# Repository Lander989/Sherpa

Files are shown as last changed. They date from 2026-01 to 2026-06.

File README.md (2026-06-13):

# SHERPA
*Tactiele GPS: een navigatiesysteem voor blinden en slechtziende dat hen tijdens hun traject begeleidt aan de hand van een tactiele wijzer dat hen de weg toont.* 

🛠️ Built by ``Corbin Braekevelt`` & ``Lander Dumont`` & ``Roland Derynck``    
🔥 Supervised by ``prof. dr. Bas Baccarne``, ``Yannick Christiaens`` & ``Wouter Devriese``    
🌱 Grown at ``Ghent University`` 🏛️ ``Industrial Design Engineering`` ([project overview](https://github.com/basbaccarne/human-centered-design))       

*14/06/2026 van de laatste update*   

## Samenvatting
Personen met een visuele beperking ervaren vaak onzekerheid tijdens het navigeren. Huidige hulpmiddelen zoals spraak-GPS vragen veel concentratie (hoge cognitieve belasting), terwijl de gebruiker vooral behoefte heeft aan geruststelling en context op aangeleerde trajecten.

Ons onderzoek werd via het Triple Diamond-model uitgevoerd. Na veldonderzoek, interviews en testen bleek dat onze eerste poging, de tactiele kaart (wave 1) te complex was om te interpreteren tijdens het wandelen. Dit leidde tot een cruciale pivot naar *SHERPA*: een intuïtief navigatietoestel met een fysiek draaibare pijl, gebaseerd op het ‘Record & Replay’-principe.

**Record:** De gebruiker (of begeleider) wandelt een traject eenmalig af. Het toestel mapt automatisch de route. Herkenningspunten en obstakels worden via spraakberichten toegevoegd, waarna de route wordt opgeslagen in een persoonlijke keuzelijst.

**Replay:** De gebruiker selecteert een traject. De pijl, aangestuurd door de ingebouwde IMU en het kompas, wijst continu de juiste richting aan. Hierdoor vallen complexe instructies weg. Dit voelbare, constante oriëntatiepunt zorgt voor mentale rust en meer zelfvertrouwen, zonder onnodige afleidingen.

> *Om dit binnen de scope van het project te realiseren, werd er voor het finale prototype voor gekozen om uitsluitend de replay-fase integraal uit te werken aan de hand van de drie develop-fases.*

<p align="center">
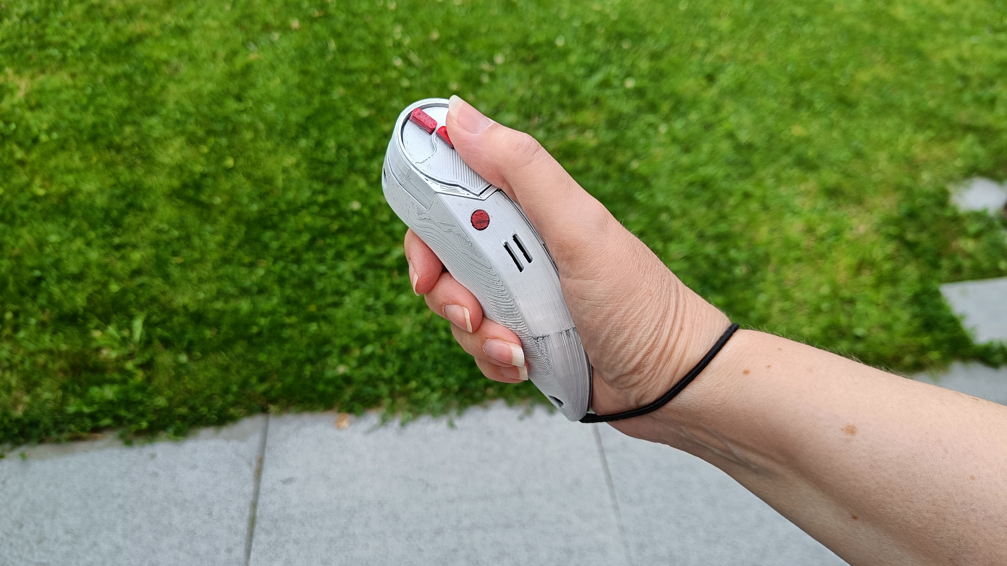
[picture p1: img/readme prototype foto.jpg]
  
</p>

## Introductie

De snelle digitalisering van de samenleving biedt kansen, maar creëert ook het risico dat personen met een visuele beperking worden uitgesloten wanneer interfaces niet toegankelijk zijn (Abdelkhalek, 2019)[^1]. Hoewel er diverse navigatiehulpmiddelen bestaan, blijft autonome navigatie in een veranderlijke omgeving een grote opgave. Het continu verwerken van complexe omgevingsinformatie vergt vaak een extreem hoge cognitieve inspanning, wat leidt tot mentale vermoeidheid en onzekerheid bij de gebruiker (Brayda et al., 2018)[^2].

Het doel van dit project is de ontwikkeling van een intuïtief hulpmiddel dat blinde personen ondersteunt bij het aanleren en onderhouden van trajecten. De focus ligt hierbij niet louter op het bereiken van een bestemming, maar op het bieden van context en geruststelling tijdens de verplaatsing. Door de mentale belasting (cognitive load) te minimaliseren, willen we de autonomie en het zelfvertrouwen van de gebruiker vergroten, zodat zij zich veiliger voelen in de openbare ruimte.

Een cruciale randvoorwaarde is dat de oplossing functioneert als aanvulling op de witte stok, specifiek voor buitengebruik (outdoor navigation). Het ontwerp moet blindelings en met één hand bedienbaar zijn, zodat het gehoor vrij blijft en de fysieke veiligheid van de gebruiker te allen tijde gewaarborgd is.

## Inhoudstafel

1. [Methodologie](./docs/methodologie.md)
2. [Discovery](./docs/discovery.md)
3. [Defintion](./docs/definition.md)
4. [Develop](./docs/develop.md)
5. [Opkomende Technologie](./docs/Opkomende%20Technologieën.md)
6. [Bill of materials](./docs/bom.md)
7. [Design Requirements](./docs/design_requirements.md)
## Kritische reflectie

<p align="center">
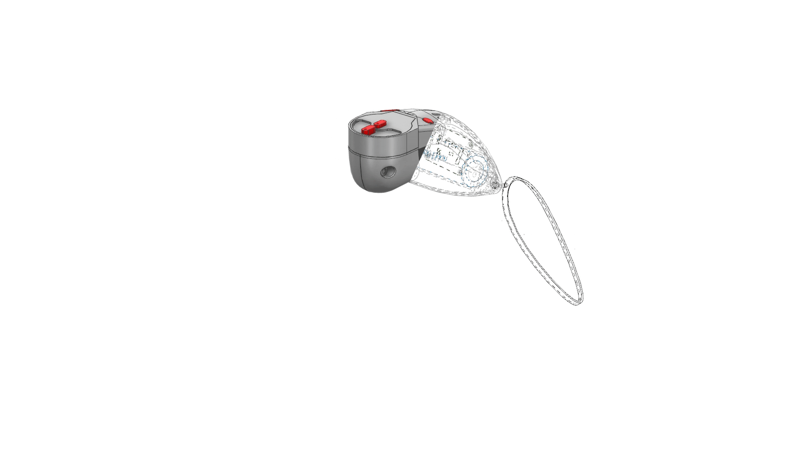
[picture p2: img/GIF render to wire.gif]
  
</p>

##### Semester 1:

Als we terugkijken op het proces van het eerste semester, was de keuze om te pivoten van de tactiele matrix naar de pijl zonder twijfel het kantelpunt. We hebben in het begin veel tijd gestoken in het matrix-concept, om er tijdens de Think Aloud-testen achter te komen dat dit cognitief veel te zwaar was voor de gebruiker. Deze validatieslag was cruciaal om te beseffen dat de gebruiker eigenlijk geen kaart wil ontcijferen, maar vooral op zoek is naar geruststelling en eenvoudige richting.

Toch moeten we kritisch zijn op onze validatie in de laatste fase. De Wizard of Oz-methode in wave 2 was perfect om het gevoel van de pijl te testen, maar het verhult de technische realiteit. Omdat wij zelf de pijl bestuurden, hielden we geen rekening met factoren zoals GPS-signaalverlies of onnauwkeurigheid in een stedelijke omgeving. We hebben dus wel de gebruikerservaring (UX) gevalideerd, maar de technische haalbaarheid is een risico dat we doorschuiven naar het volgende semester.

Daarnaast is onze testgroep (N=4) vrij homogeen gebleven. Onze respondenten, zoals Pieter-Jan, zijn al erg zelfstandig en mobiel. Hierdoor bestaat het risico dat we een oplossing hebben ontworpen voor een ‘best-case scenario’. Het is voor ons een belangrijk werkpunt om in de toekomst te testen met mensen die onzekerder zijn in het verkeer, om te zien of het ‘Record & Replay’-concept hen ook voldoende vertrouwen biedt.
##### Semester 2 
Aan het einde van de definitiefase concludeerden we dat ons product zich meer moest richten op blinden en slechtzienden die minder zelfredzaam en onzekerder in het verkeer zijn. In de praktijk bleek deze specifieke subdoelgroep echter uiterst moeilijk te bereiken, mede doordat zij zich minder vaak aansluiten bij belangenverenigingen. Hierdoor is het ons helaas niet gelukt om hen actief in ons verdere ontwerpproces te betrekken.

De waarde van continue, directe input vanuit de doelgroep kan simpelweg niet overschat worden. Dat we naar het einde van het project toe het contact met enkele van onze kerngebruikers verloren, was dan ook een flink nadeel. Dit had een direct negatieve impact op het afronden van ons onderzoek en bemoeilijkte het nemen van finale designbeslissingen.

Deze factoren hebben er mede toe geleid dat we onze vooropgestelde einddoelen niet volledig hebben behaald. Tijdens de finale outdoortesten kwamen bovendien technische pijnpunten aan het licht, waarbij vooral de onnauwkeurigheid van de GPS een aanzienlijk struikelblok vormde. Hoewel het huidige prototype een sterke basis vormt en de absolute meerwaarde van het concept aantoont, is het product technisch gezien nog lang niet klaar voor een marktintroductie.

Desondanks kijken we bijzonder positief terug op dit project. We hebben de kans gekregen om ons onder te dompelen in een voor ons compleet nieuwe wereld en we hebben enorm inspirerende mensen ontmoet. Bovenal heeft het ons als ontwerpers een veel scherpere en kritische blik gegeven op de manier waarop de maatschappij—en onze fysieke leefomgeving—zich al dan niet aanpast aan personen met een visuele beperking.

## Noot inzake het gebruik van AI
Binnen dit project is Gemini ingezet als ondersteunende AI-tool, met een strikt afgebakende rol:

* **Rapportage:** Het structureren van ruwe notities en het taalkundig verfijnen van teksten.
* **Development:** Ondersteuning bij het schrijven van de HTML-website.

> *AI werd nadrukkelijk niet ingezet voor inhoudelijke analyses of het bepalen van ontwerpbeslissingen en design requirements; deze fundamenten zijn uitsluitend gebaseerd op direct veldonderzoek en kritische teamreflectie.*

## Bijlagen
#### Discovery
* Literatuuronderzoek (N=16)

  [- Lander: Protocol literatuurstudie](<./reports and protocols/Protocol Literatuur Studie.pdf>)
  
  [- Roland: Protocol benchmarking](<./reports and protocols/Competitor analysis.pdf>)
  
  [- Corbin: Protocol benchmarking](<./reports and protocols/benchmarking_protocol_corbin_braekevelt.pdf>)
    
  [- Lander: Rapport literatuurstudie](<./reports and protocols/Rapport Literatuur Studie.pdf>)
  
  [- Roland: Rapport benchmarking](<./reports and protocols/Competitor analysis.pdf>)
  
  [- Corbin: Rapport benchmarking](<./reports and protocols/benchmarking_raport_corbin_braekevelt.pdf>)
* Interviews (N=12)

   [- Lander: Protocol interviews](<./reports and protocols/Protocol Interviews.pdf>)
  
   [- Roland: Protocol interviews](<./reports and protocols/Interviewprotocol_slechtzienden_!.pdf>)
  
   [- Corbin: Protocol interviews](<./reports and protocols/Interview-protocol-Corbin_Braekevelt.pdf>)

   [- Lander: Rapport interviews](<./reports and protocols/Rapport Interviews.pdf>)
  
   [- Roland: Rapport interviews](<./reports and protocols/Analyse respondenten rapport.pdf>)
  
   [- Corbin: Rapport interviews](<./reports and protocols/Interview-raport-Corbin_Braekevelt.pdf>)
    
#### Definition
* User testing wave 1 (N=6)
  * [Protocol](<./reports and protocols/Protocol Wave 1.pdf>)
  * [Rapport](<./reports and protocols/Verslag_wave1.pdf>)
* User testing wave 2 (N=2)
  * [Protocol](<./reports and protocols/Protocol Wave 2.pdf>)
  * [Rapport](<./reports and protocols/Rapport Wave 2.pdf>)

#### develop
* User testing develop 1 (N=5)
  * [protocol](<./reports and protocols/protocol_Deelopdracht 3 develop 1.pdf>)
  * [rapport](<./reports and protocols/Verslag_Deelopdracht 3 develop 1.pdf>)

* User testing develop 2 (N=5)
  * [protocol](<./reports and protocols/protocol_develop_2.pdf>)
  * [rapport](<./reports and protocols/Rapport_develop_2.pdf>)

* User testing develop 3 (N=2)
  * [protocol](<./reports and protocols/protocol_develop_3.pdf>)
  * [rapport](<./reports and protocols/Rapport_develop_3.pdf>)

## Licentie

This repository contains both software and design materials created as part of an industrial design energineering project at Ghent University.

- **Software and code:** [MIT License](./LICENSE-MIT)  
- **Design, documentation, CAD, and media:** [CC BY 4.0 License](./LICENSE)
  
You are free to reuse and build upon this work, both commercially and non-commercially, as long as proper attribution is given to the original authors.

## Bronnen
 [^1]:Abdelkhalek, M. (2019). Final Year Project Report - Blind Pad. University of Bath

 [^2]:Brayda, L. et al. (2018). Updated Tactile Feedback with a Pin Array Matrix. Micromachines, 9(7), 351

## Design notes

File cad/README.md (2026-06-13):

# SHERPA — CAD & 3D-Modellen

In de map `cad` vind je zowel het ZIP-archief van ons project met de originele PRT-bestanden (Siemens NX), als de STL-bestanden die volledig gereed zijn voor 3D-printing.

### Beschikbare bestanden:
* **Compleet CAD-model:** [SHERPA assembly](./PRT/Sherpa_Final.zip)
* **STL-bestanden:**

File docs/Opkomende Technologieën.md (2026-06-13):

# Opkomende Technologieën
## Inleiding
In het kader van het vak Opkomende Technologieën (OT) werken we een MVP-variant uit van de SHERPA-wegwijzer uit het project Gebruiksgericht Ontwerpen (GGO). In het vak OT is de onderbouwing uit GGO minder van toepassing. De nadruk ligt op het uitwerken van een technisch uitdagend prototype waarbij verschillende competenties worden getoetst en samenkomen.

### GGO
Het product en doelstellingen uit GGO zien er als volgt uit:

**Product:** Navigatiehulpmiddel voor blinden en slechtzienden

**Doel:**
Gebruikers een manier geven om sneller en zelfstandiger onbekende routes aan te leren en onderhouden.

Productdoelstellingen:
1. Gebruikers kunnen een traject zelfstandig afleggen zonder hulp van derden  
2. Gebruikers kunnen met hulp van derden trajecten opnemen  
3. Gebruikers ervaren continu oriëntatie en vertrouwen tijdens het gebruik  
4. Gebruikers blijven fysiek veilig tijdens navigatie  
5. Het systeem vereist minimale training en mentale inspanning

<p align="center">
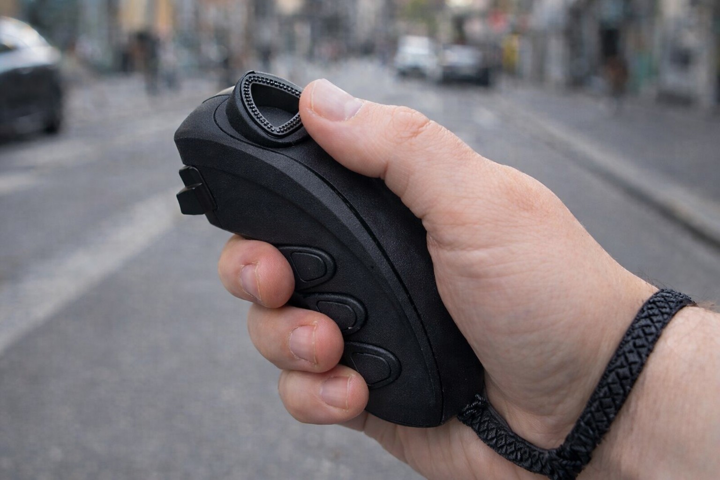
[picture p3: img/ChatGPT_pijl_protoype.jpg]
  
  <br>
  <em>Visualisatie van de SHERPA-wegwijzer.</em>
</p>

Dit heeft zich kortweg vertaald naar een mobiel navigatiesysteem dat met een wijzer de weg wijst doorheen een opgenomen traject. Op deze wijze wordt een blinde van punt naar punt via de veiligste weg geleid. Hierover valt uitgebreid te lezen in het GGO-gedeelte van deze GitHub.

## Opdracht

Voor OT kijken we naar de technische uitdagingen. Dit zijn volgende punten:

- Waar is de persoon: GPS data uitlezen intepreteren en gebruiken.

- Traject opslaan: Data opslaan en opnieuw ophalen.

- Naar waar kijkt de persoon: Kijkrichting van de gebruiker bepalen met een IMU.

- Wijzer richten: Servo aansturen zodat deze altijd naar het volgende waypoint wijst.

- Algemene besturing van toestel: Inputs toevoegen zodat de gebruiker het toestel kan gebruiken.

- Op afstand het systeem uitlezen en de data weergeven op een HMI: Connectiviteit wifi/bluethoot, dashbord waar data weergegeven wordt om troubleshooting te bevorderen.

## Richtingbepaling
Doel

De wijzer moet het volgende waypoint aanwijzen. Hier is de vraag: hoe weet de wijzer naar waar hij moet wijzen? De volgende afbeelding illustreert hoe de hoek bepaald wordt. Het magnetische noorden dient als nullijn. In wijzerszin loopt de hoek van 0 tot 360 graden op. Soms komen [0,180] en [-180,0] voor in de berekeningen. Onthoud dat de heading en bearing altijd genormaliseerd worden naar een waarde tussen 0 en 360 graden. Het verschil tussen de heading en bearing noemen we delta. Met delta kan theta gevonden worden. Theta stuurt de hoek van de servo.

Met een IMU bepalen we de heading. De bearing bepalen we aan de hand van de huidige locatie en het doelwit. De huidige locatie halen we op met een GPS. Het doelwit is een van de opgeslagen coördinaten.

<p align="center">
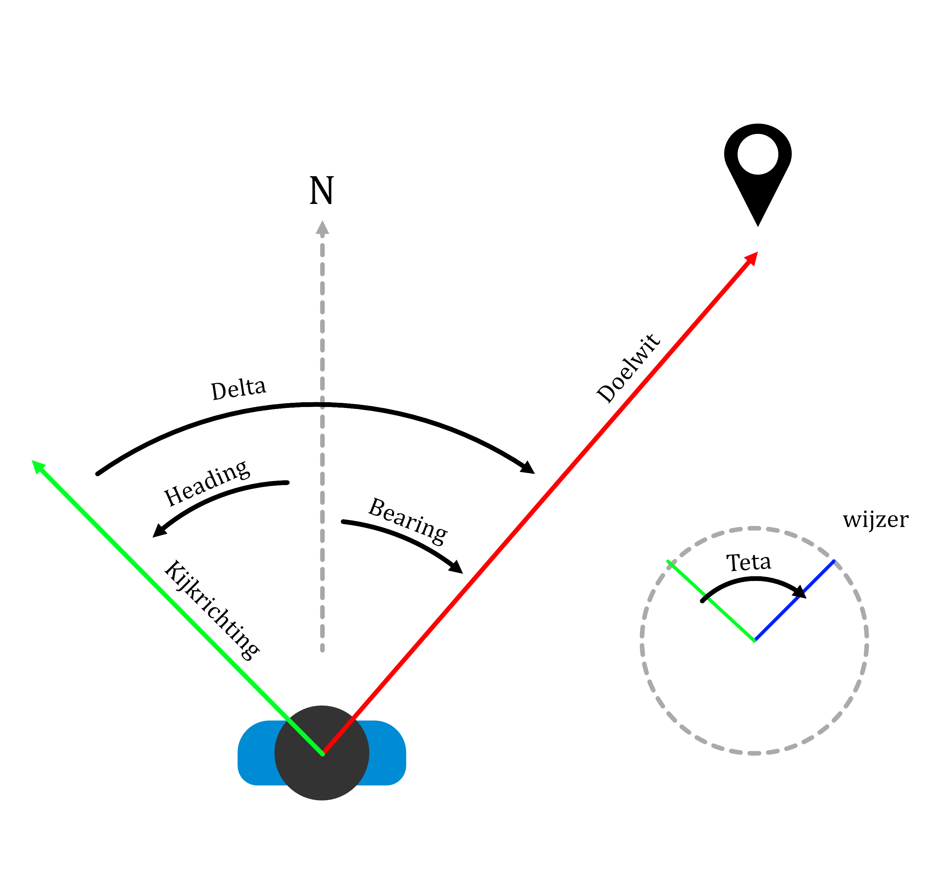
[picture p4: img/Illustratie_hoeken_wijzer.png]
  
  <br>
  <em>Illustratie van heading, bearing, delta en theta.</em>
</p>

## Onderdelen

#### IMU
We maken gebruik van een grove 9DOF-IMU. Deze sensor bevat een accelerometer, gyrometer en magnetometer.

De meegeleverde voorbeeldcode uit de bibliotheek is onbruikbaar. Deze bevat geen tiltcompensatie en sensorfusion. De volgende Instructables-post gebruiken we als basis om onze sensoren uit te lezen en om te zetten in nuttige, stabiele informatie.

>https://www.instructables.com/Tilt-Compensated-Compass/

Hiermee zijn we in staat om accuraat de kijkrichting van de persoon te bepalen, ongeacht de oriëntatie van de sensor.
#### GPS
De GPS is in staat om binnen de 2 meter zijn positie te bepalen. Dit coördinaat update constant. De bibliotheek TinyGPS++ bevat een bearingfunctie die bij ingave van twee coördinaten de bearing teruggeeft.

#### Inputs en outputs
De gebruiker bestuurt het toestel met twee knoppen. De knoppen zijn NO-drukknopjes. We verbinden ze met pulldownweerstanden aan de microcontroller. Het toestel bevat ook een trilmotor voor vibratiefeedback. De trilmotor wordt aangestuurd met een PWM-signaal. Dit maakt het mogelijk om verschillende patronen af te spelen.

####  Schakeling
Volgende afbeelding toont de schakeling schematisch.

<p align="center">
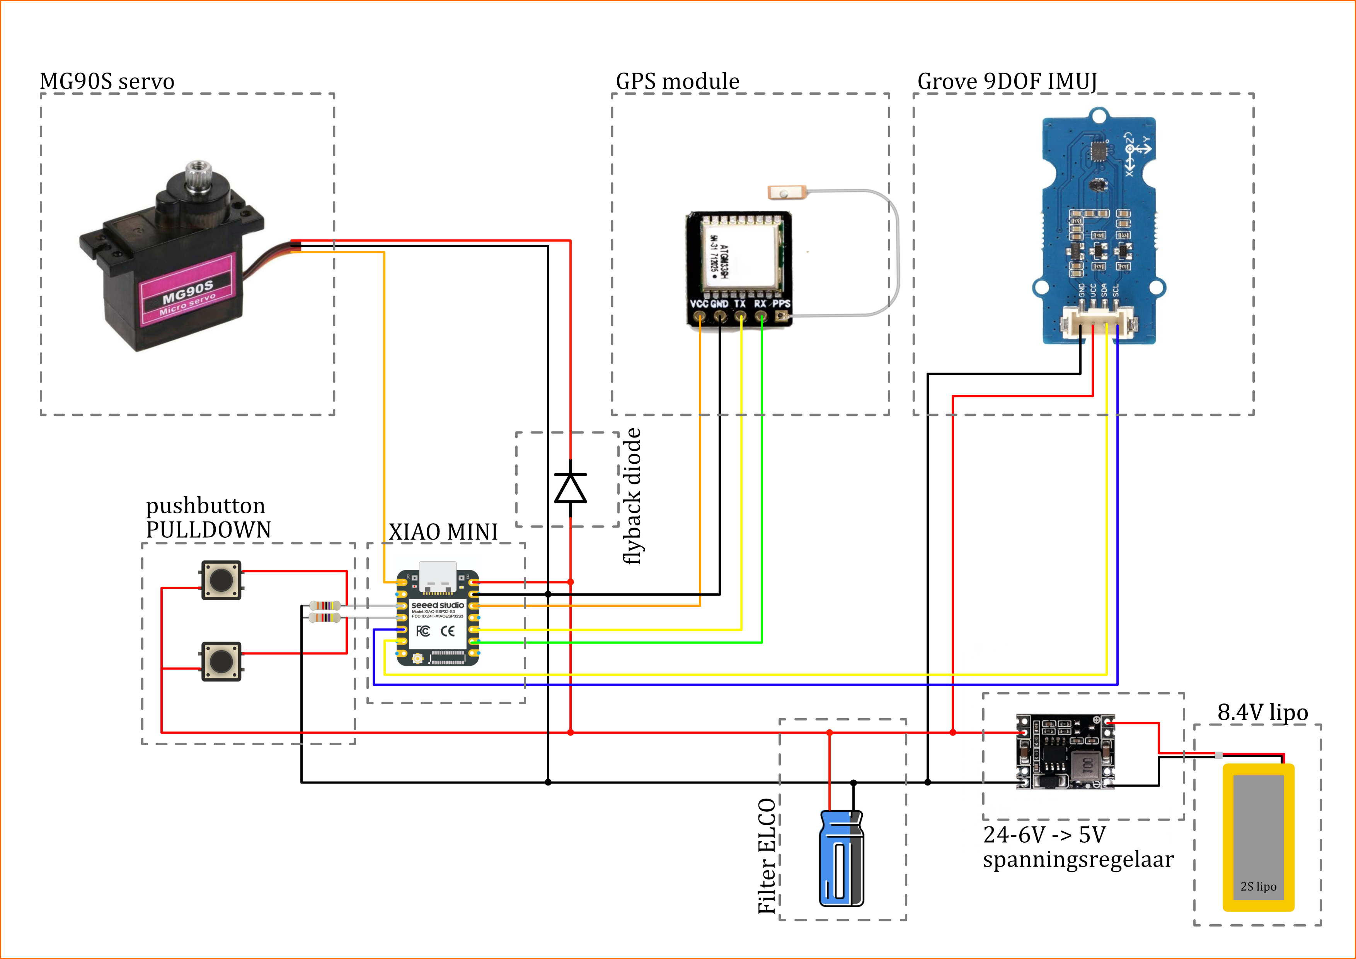
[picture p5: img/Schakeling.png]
  
  <br>
  <em>Schematische voorstelling van de schakeling.</em>
</p>
Dit schema uitgewerkt in een eerste prototype ziet er chaotisch uit. Maar alles is aanwezig om de functionaliteit te testen. Hierna kan de geteste en werkende versie in een afgewerkte omhuizing worden gestoken.
<p align="center">
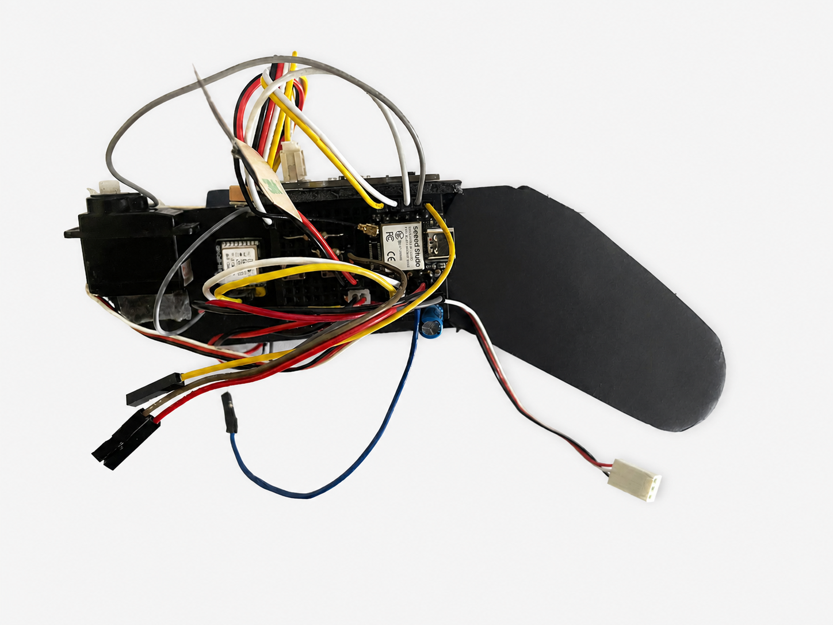
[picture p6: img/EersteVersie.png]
  
  <br>
  <em>Eerste werkende prototype van de schakeling.</em>
</p>

## Traject

Tijdens het ontwikkelen van de prototypes maakten we gebruik van Google Earth om routes uit te stippelen. Deze route bestaat uit een lange lijst van latitude- en longitudecoördinaten. Het toestel weet wanneer een punt gepasseerd wordt en schakelt vervolgens over naar het volgende waypoint.

Het is de bedoeling dat de gebruiker later zelf trajecten kan opnemen. Hierbij wordt de lijst met punten automatisch aangemaakt door het toestel terwijl een traject wordt afgelegd. Om de ongeveer 2 meter zou dan een nieuw punt worden opgeslagen. Deze functionaliteit werd echter niet verder uitgewerkt wegens tijdsgebrek. 

## Visualiseren van het traject
<p align="center">
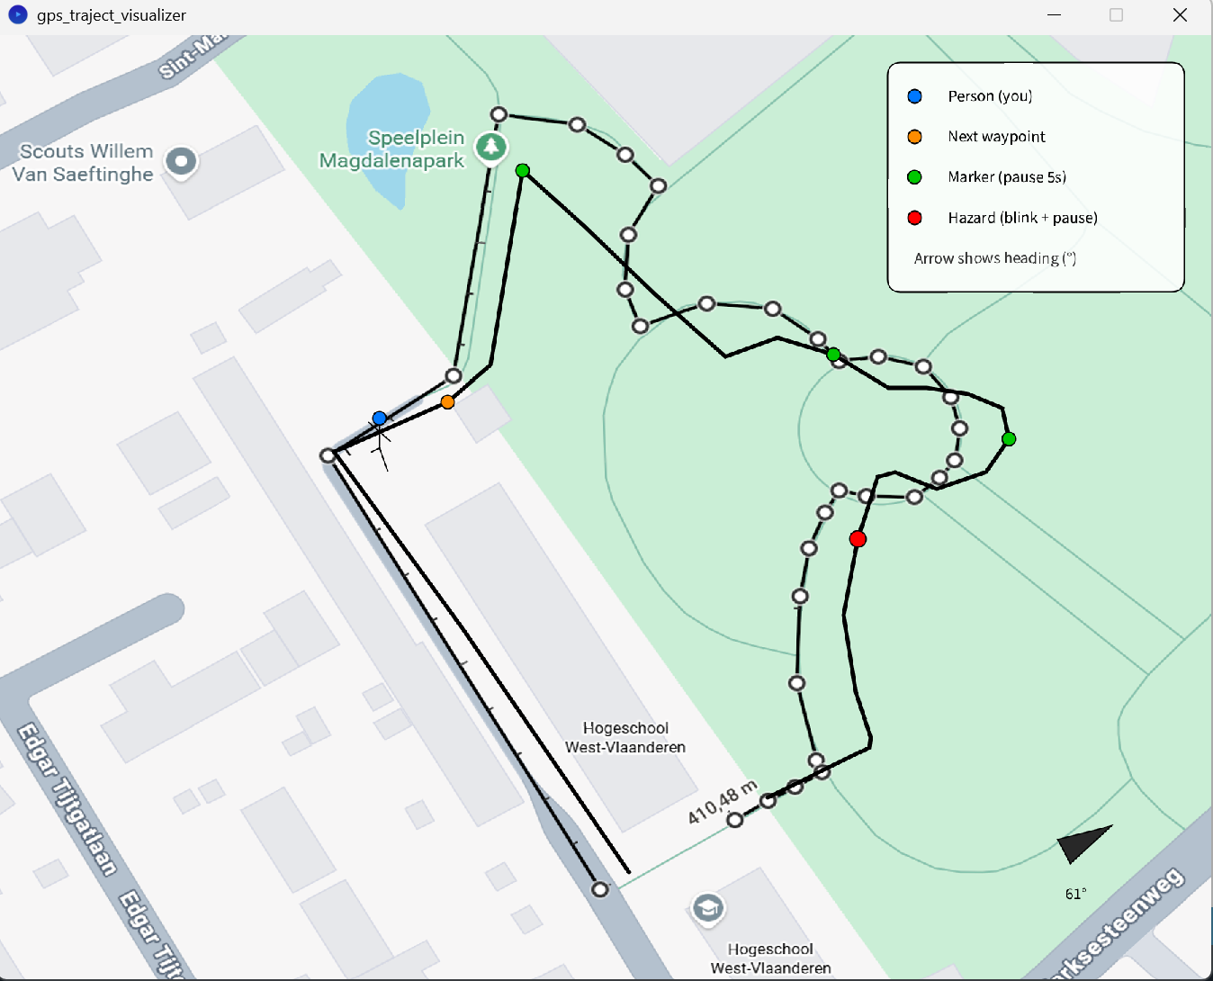
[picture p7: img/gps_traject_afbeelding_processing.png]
  
  <br>
  <em>Visualisatie van het GPS-traject in Processing.</em>
</p>
In de eerste fase van het project werd een visualisatie ontwikkeld in Processing. Hierbij werden GPS-datapunten handmatig geëxtraheerd uit Google Maps en ingelezen om het traject statisch uit te tekenen.

Het traject op de afbeelding komt, zoals te zien, niet volledig overeen met het traject op Google Maps. Dit komt door de platte 2D-weergave van onze kaart ten opzichte van de werkelijke 3D-kromming van de aarde, wat een verschuiving veroorzaakt. Daarnaast trekt onze weergave een rechte lijn tussen twee punten, waardoor bochten worden afgesneden.

Omdat de ESP32 fungeert als een lokale webserver en continu livecoördinaten doorstuurt, zijn we voor de definitieve opstelling overgestapt naar een dynamische, webgebaseerde (HTML-)visualisatie. Dit maakt het mogelijk om de ontvangen data veel efficiënter en in realtime weer te geven.

## Validatietest
Om de effectiviteit, integratie en nauwkeurigheid van het systeem in de praktijk te verifiëren, is het traject fysiek afgelegd tijdens een veldtest. De eerste GIF demonstreert de dynamische werking van de wijzer. Deze past zich in realtime aan op basis van de actuele kijkrichting (heading) van het toestel ten opzichte van het volgende waypoint.

<p align="center">
  
  <br>
  <em>Realtime aanpassing van de wijzer tijdens navigatie.</em>
</p>

De tweede GIF toont de navigatie door een scherpe bocht. Hierbij is te zien hoe de binnenkomende data van de ESP32 nauwkeurig wordt geregistreerd op het webdashboard, terwijl de fysieke wijzer synchroon en correct het volgende waypoint aanduidt.

<p align="center">
  
  <br>
  <em>Validatietest tijdens een scherpe bocht.</em>
</p>

## Afwerking

Het werkende prototype werd in een afgewerkte behuizing ingebouwd. Hiermee hebben we testen uitgevoerd voor het vak GGO.

<p align="center">
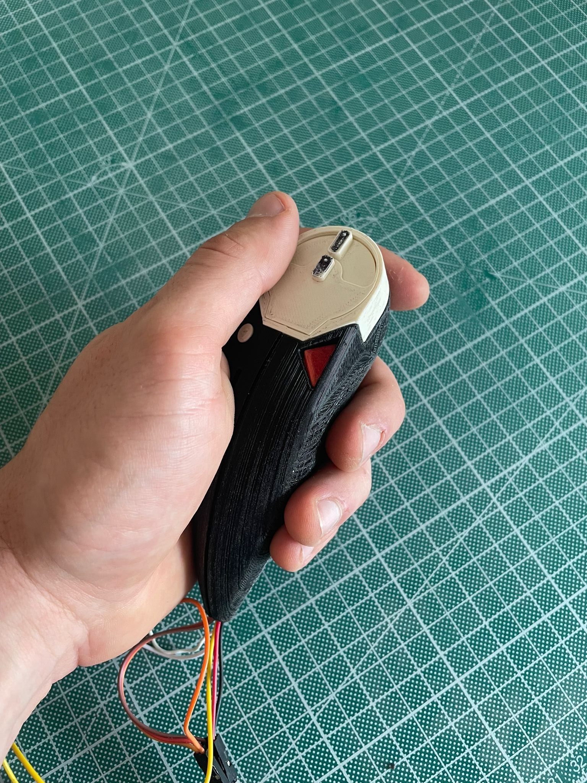
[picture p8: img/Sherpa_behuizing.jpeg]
  
  <br>
  <em>Afgewerkte behuizing van het prototype.</em>
</p>

## Code

Hier is de finale code: [GPS_IMU_TEST_V3_ESP32](https://github.com/Lander989/Sherpa/blob/main/src/Opkomende%20Technelogie%C3%ABn/GPS_IMU_TEST_V3_ESP32/GPS_IMU_TEST_V3_ESP32.ino)

## Kritische reflectie

Tijdens de finale test bleken er toch wat onnauwkeurigheden naar boven te komen, vooral bij de GPS, die maar accuraat is tot op 2 meter. Dit bracht vervelende situaties met zich mee, aangezien de punten die op Google Earth nog op het wandelpad lagen, zich tijdens de test soms in een gebouw of in de struiken bevonden.

Voor het einddoel van de Sherpa, namelijk het veilig navigeren van blinden en slechtzienden, vormt deze afwijking een kritiek punt.

Een mogelijke oplossing is de overstap naar een dualband-GPS-module. Deze modules combineren meerdere frequenties, waardoor ze aanzienlijk accurater zijn en minder last hebben van signaalreflecties dicht bij gebouwen of bomen.

De ESP32 gebruiken als lokale webserver was de simpelste manier om de data draadloos naar de computer te sturen. Maar dit komt met een groot nadeel dat tijdens het testen duidelijk werd. Zolang jouw laptop verbonden is met de ESP32, heb je geen internet. Hierdoor kunnen we de kaartafbeelding niet updaten.

Bluetooth Low Energy zou een betere optie zijn geweest. Maar we kregen de data niet uitgelezen op de computer. Daarom kozen we ervoor om de webserver te gebruiken.

## Noot inzake het gebruik van AI
In dit project werd Gemini Pro gebruikt bij het coderen van de visualisatie, zowel voor Processing als voor de finale HTML-website. Ook werd de tekst grammaticaal scherpgesteld door Gemini.

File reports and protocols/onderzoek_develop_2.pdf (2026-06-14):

# Sherpa develop 2 onderzoeksrapport

## Wat willen we onderzoeken in deze fase

- Nodige functies linken aan de nodige knoppen.

Het product moet instaat zijn om verschillende functies uit te voeren. Deze functies moeten gelinkt worden aan user inputs, deze zullen komen van verschillende knoppen (drukknoppen, slider, triggers, …) en andere componenten (zoals bv. een microfoon).
- Positie van de knoppen op product.

De gedefinieerde knoppen zullen ook hun eigen plaats op het product krijgen. De plaats van deze knoppen moet logisch en comfortabel zijn voor de gebruiker.
- Welke houding neemt de gebruiker aan.

Bij het gebruik van het product zal de gebruiker deze op een bepaalde manier vasthouden, dit zal onderzocht worden. Ook zal er gekeken worden naar hoe het product ervoor zorgt dan de gebruiker bewust of onbewust een comfortabele en ergonomische positie aanneemt.
- Vorm van het product aanpassen.

Doormiddel van prototypes de product vorm en button lay-out testen en verbeteren.
- Elektronica verwerken.

Kijken of alle nodige elektronica en componenten in het product passen. Zo niet een oplossing bedenken.

## Benchmarking

Elke controller is onderzocht op vorm, button layout en ergonomie.

## 1. DJI RC Motion 3

Vorm & Dimensies
- Compacte, handheld design speciaal ontworpen voor drone-besturing
- Gemiddelde lengte: ongeveer 15-17 cm
- Breedte: circa 8-10 cm
- Asymmetrisch ontwerp dat goed aansluit op de hand
Button Layout
- Twee analoge joysticks in het midden (thumbstick positie)
- Trigger-knoppen aan de bovenkant (voor duim bereikbaar)
- Multifunctionele knoppen aan de zijkanten

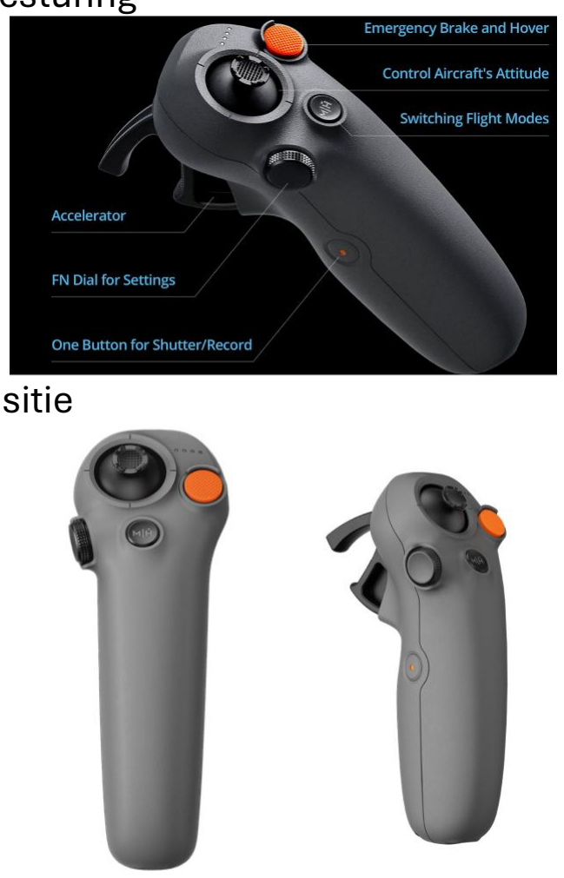
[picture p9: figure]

- Goed verspreide lay-out voor snelle toegang zonder hand-repositie Ergonomische Kenmerken
- Grip diameter: ongeveer 30-35 mm
- Grip lengte: geoptimaliseerd voor gemiddelde handen
- Ergonomische sculptuur voor palm- en vingerondersteuning
- Antislip materiaal op contactoppervlakken

## 2. Meta Quest 3 Touch Controller

Vorm & Dimensies
- Ergonomisch ontworpen voor VR-toepassingen
- Lengte: ongeveer 13-14 cm
- Grip omvang: 35-40 mm
- Geïntegreerde hand tracking band aan bovenkant Button Layout
- Joystick aan voorkant (duim-bereik)
- X/Y en A/B knoppen langs zijkant
- Grip-knoppen aan beide zijkanten (wijsvinger)
- Trigger aan voorkant (wijsvinger-bediening) Ergonomische Kenmerken
- Asymmetrisch design voor linker- en rechterhand
- Licht gewicht (circa 150g) voor langdurig gebruik
- Natuurlijke greep houding ondersteund door vorm

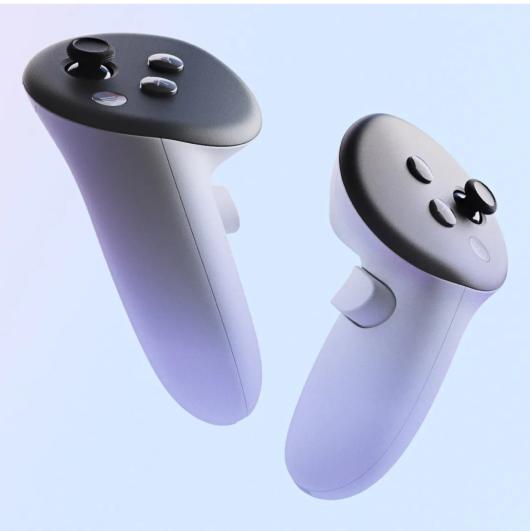
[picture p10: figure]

## 3. Nintendo Wii Remote

Vorm & Dimensies
- Rechthoekig, straight-bar design
- Lengte: ongeveer 15 cm
- Breedte: circa 5 cm
- Zeer compacte en lichte constructie
Button Layout
- D-pad aan voorkant
- A-knop en B-knop onder (duim + wijsvinger bereik)
- Home en Power knoppen aan bovenkant
- Zeer eenvoudige, minimalistische button-indeling Ergonomische Kenmerken
- Zeer licht gewicht (ongeveer 150g)

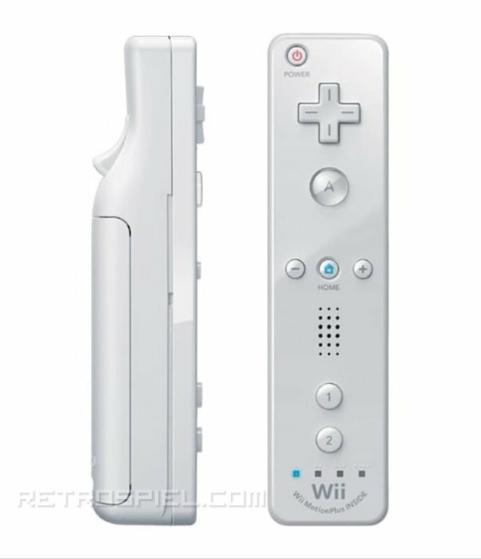
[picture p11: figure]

- Ingebouwde motion-sensoren (accelerometer, gyroscoop)
- Eenvoudige grip zonder veel anatomische sculptuur
- Geschikt voor alle leeftijden en handgroottes

## 4. PlayStation DualSense Controller

Vorm & Dimensies
- Symmetrisch, ergonomisch gebogen design
- Lengte: ongeveer 16 cm
- Breedte: ongeveer 11 cm
- Gewicht: circa 280g
Button Layout
- Twee analoge joysticks (standaard positie)
- Vier face-buttons (driehoek, cirkel, X, vierkant)
- Shoulder buttons (L1, R1, L2, R2)
- Touchpad aan bovenkant
- PlayStation-knop en options/share knoppen

Ergonomische Kenmerken
- Grip diameter: ongeveer 35-40 mm
- Grip lengte: ongeveer 120 mm
- Diepe grip curves voor comfort tijdens lang gebruik
- Textuur op grip-oppervlak
- Haptic feedback en adaptieve triggers

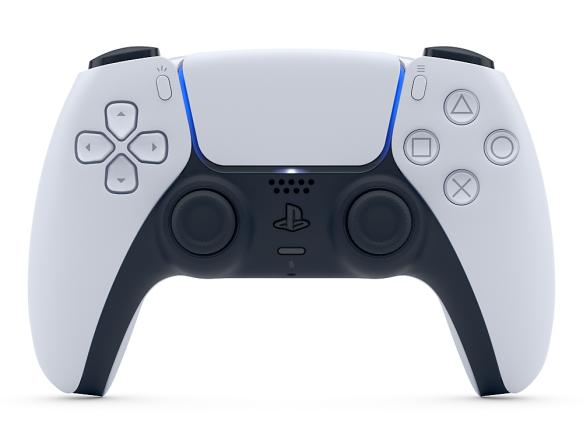
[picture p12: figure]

## Vergelijkende Analyse

Samenvatting per Categorie
Aspect | DJI RC Motion 3 | Meta Quest 3 | Wii Remote | DualSense
Grip Diameter | 30-35 mm | 35-40 mm | ~50 mm | 35-40 mm
Lengte | 15-17 cm | 13-14 cm | ~15 cm | ~16 cm
Symmetrisch | Nee | nee | Ja | Ja

Belangrijkste Inzichten
Grip Diameterrange
De onderzochte controllers variëren van 30-75 mm in grip diameter. De Sherpa design-doelstelling van 28-37 mm (op basis van het 5e percentiel) past goed in het onderste bereik, geschikt voor kleinere handen en precisiewerk.

Button Layout Strategie
Alle referentie-controllers gebruiken een combinatie van analoge inputs (joysticks) en discrete knoppen. De Wii toont dat minimalisme werkt voor brede doelgroepen.

## Mappen van inputs

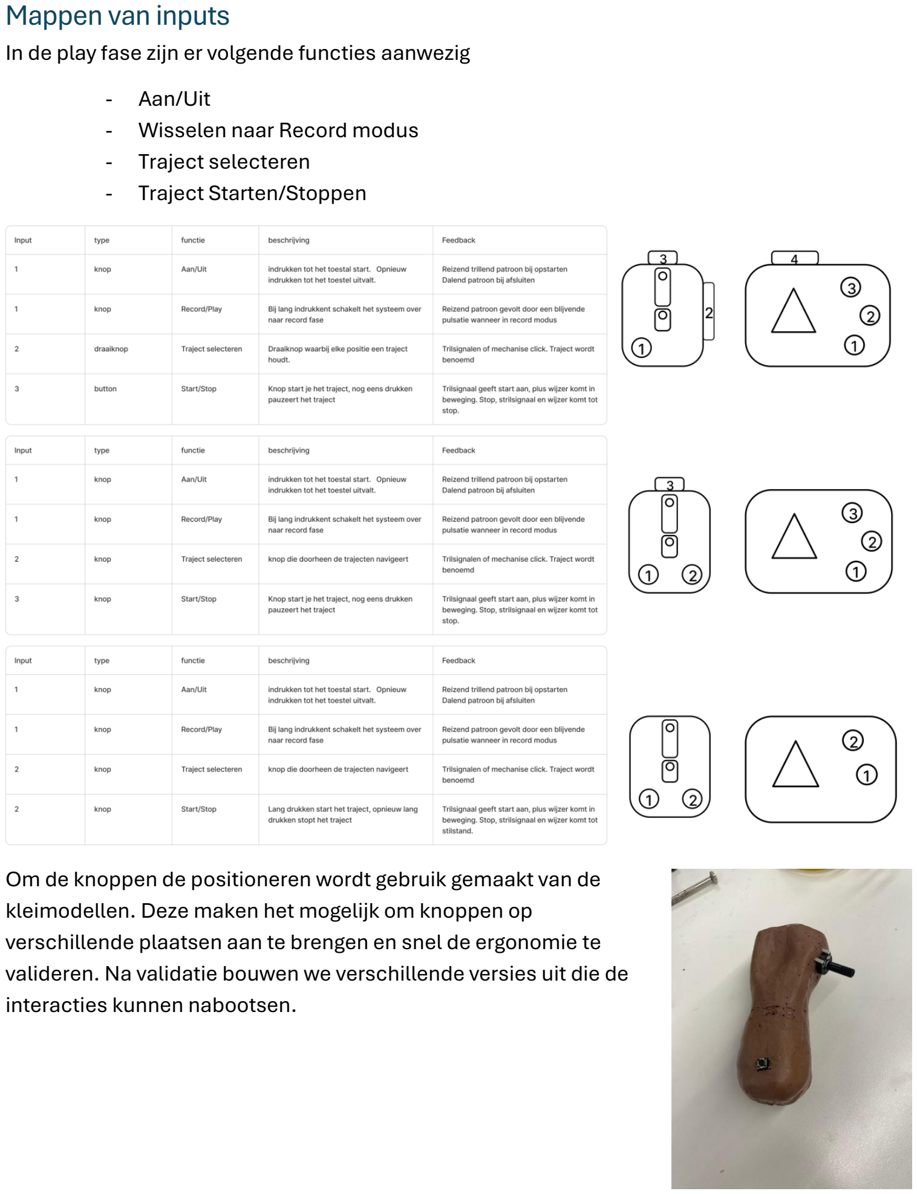
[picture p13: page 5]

In de play fase zijn er volgende functies aanwezig
- Aan/Uit
- Wisselen naar Record modus
- Traject selecteren
- Traject Starten/Stoppen

Om de knoppen de positioneren wordt gebruik gemaakt van de kleimodellen. Deze maken het mogelijk om knoppen op verschillende plaatsen aan te brengen en snel de ergonomie te valideren. Na validatie bouwen we verschillende versies uit die de interacties kunnen nabootsen.

## Ergonomie onderzoek

Rond ergonomie zijn er in het verleden al voldoende onderzoeken rond gebeurd. Voor deze opdracht is er dan ook geen tijd beschikbaar om zelf volwaardig onderzoek te doen rond de ergonomie van het lichaam, meebepaald de hand. Hierdoor wordt bij deze deelopdracht gebruikgemaakt van onderzoeken en researchpapers van andere onderzoekers. Antropometrische Data
De diameter van het handvat wordt ontworpen op
basis van het 5e percentiel, zodat zowel kleine als
grote handen het handvat comfortabel kunnen omvatten. Deze maat wordt enkel in de breedte aangeduid op de afbeelding gerespecteerd. In de lengte mag het groter zijn (richting van de wijsvinger). De lengte van het handvat wordt afgestemd op de handbreedte, waarbij het 95e percentiel wordt gehanteerd, zodat ook gebruikers met grotere handen het handvat volledig kunnen vastgrijpen.
De volgende data is afkomstig van de DINED-database:

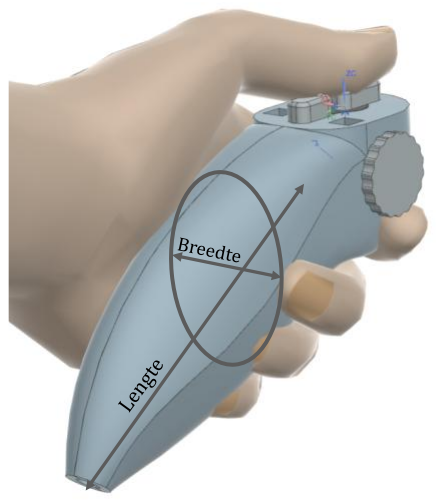
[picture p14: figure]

Tilley en Dreyfuss hebben in hun onderzoek "The Measure of Man and Woman" (1974) gedetailleerde afmetingen van mannelijke en vrouwelijke handen gedocumenteerd. Deze data omvatten kritieke maten zoals handlengte, handbreedheid, en vingerlengtes. Robinson (in het "Anthropometric Hand Measurements") complementeert dit met aanvullende afmetingen voor grip-analyse.

Percentiel | 5% | 50% | 95%
Greep diameter | 34,37 | 41,06 | 47,75
Handbreedte | 71 | 84 | 97

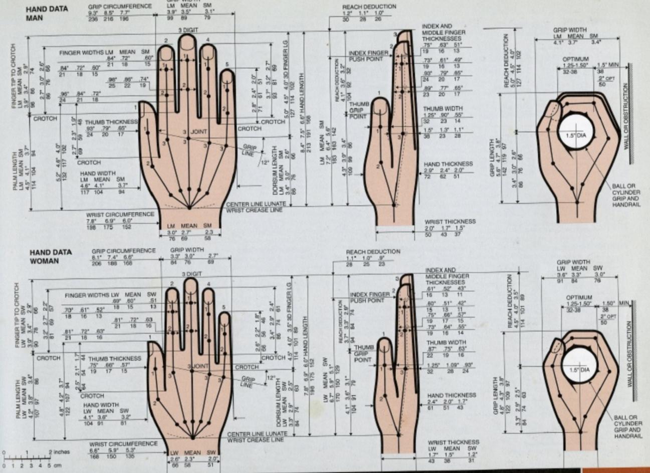
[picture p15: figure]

Een gemiddelde mannelijke handlengte bedraagt ongeveer 188,8 mm, terwijl vrouwelijke handen gemiddeld 182,1 mm zijn. De handbreedheid varieert van ongeveer 72,5 mm (vrouw) tot 86,5 mm (man). Deze variatie is essentieel voor het ontwerp van een product dat voor diverse gebruikers ergonomisch geschikt is.
Greep geometrie
Onderzoeken tonen aan dat de optimale handvatdiameter tussen 28-37 mm ligt voor een neutrale greephouding. De waarde van het gekozen percentiel valt met 34 mm hier in. González et al. (2018) demonstreerden dat een geparametriseerde handvatontwerp, geschaald naar individuele palmlengte (PLM), optimale ergonomie oplevert. Voor de PLM is er geen dataset te vinden.
Voor langdurig gebruik is een cilindrisch of licht anatomisch gevormde handgreep essentieel. De greep moet voldoende contactoppervlak bieden om druk evenwichtig over palm en vingers te verdelen. Dit minimaliseert vermoeiding en voorkomt concentratie van druk op gevoelige gebieden.

De handvatlengte zou minimaal 100-120 mm bedragen om voldoende stabiliteit en controle te bieden. De waarde van het gekozen percentiel komt hier ongeveer mee overeen.
Een helling van 45° tussen handvat en de voorkant van het product zorgt voor een natuurlijke polshouding.

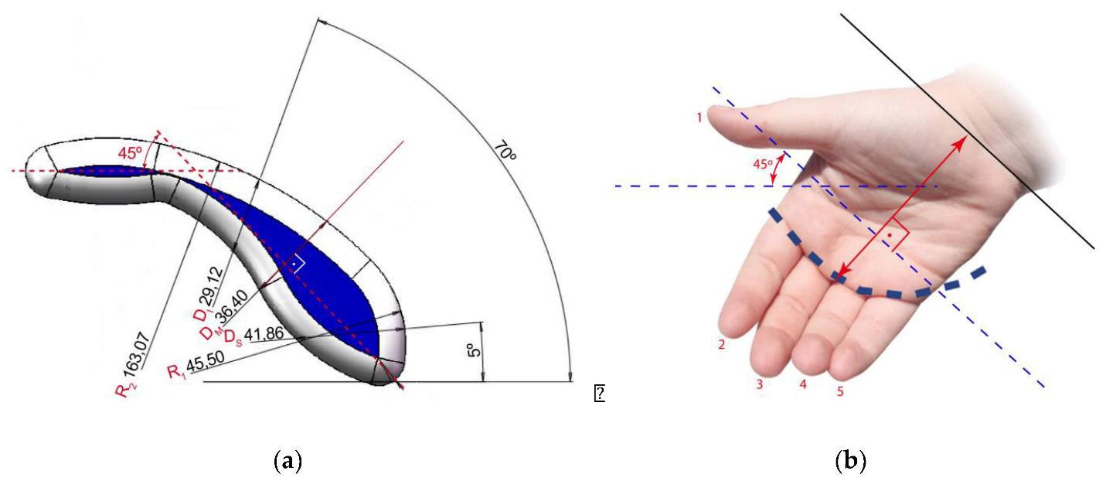
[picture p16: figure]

Knoppen dienen gepositioneerd te worden in bereik van duim, wijsvinger en middelvinger in neutrale hand-positie. Op basis van antropometrische data:
- Duim: bereik van 0-40 mm vanaf palmzijde
- Wijsvinger: bereik van 50-80 mm langs bovenzijde handvat
- Middelvinger: bereik van 30-60 mm vanaf palmzijde
Knoppen voor frequent gebruik moeten zich op maximaal bereikbare posities bevinden zonder polsflexie.
Langdurig controllergebruik vereist een neutrale polshouding. Dit betekent:
- Pols in lichte extensie (5-10°)
- Geen radiale of ulnaire deviatie
- Elleboog flexie van ongeveer 90°
- Arm steun op gewenste hoogte
Het productontwerp dient deze houding passief te ondersteunen, zodat gebruikers zich kunnen concentreren op de interactie zonder fysieke compensatie.

Conclusie

Voor dit project kan er dus gebruikgemaakt worden van deze bevindingen. De belangrijkste afmetingen om rekening me te houden zijn dus: een diameter van 28-37 mm, lengte van minimaal 110 mm, en anatomisch optimale knopplaatsing. Het toepassen van deze maten zorgen voor langdurig comfortabel gebruik.

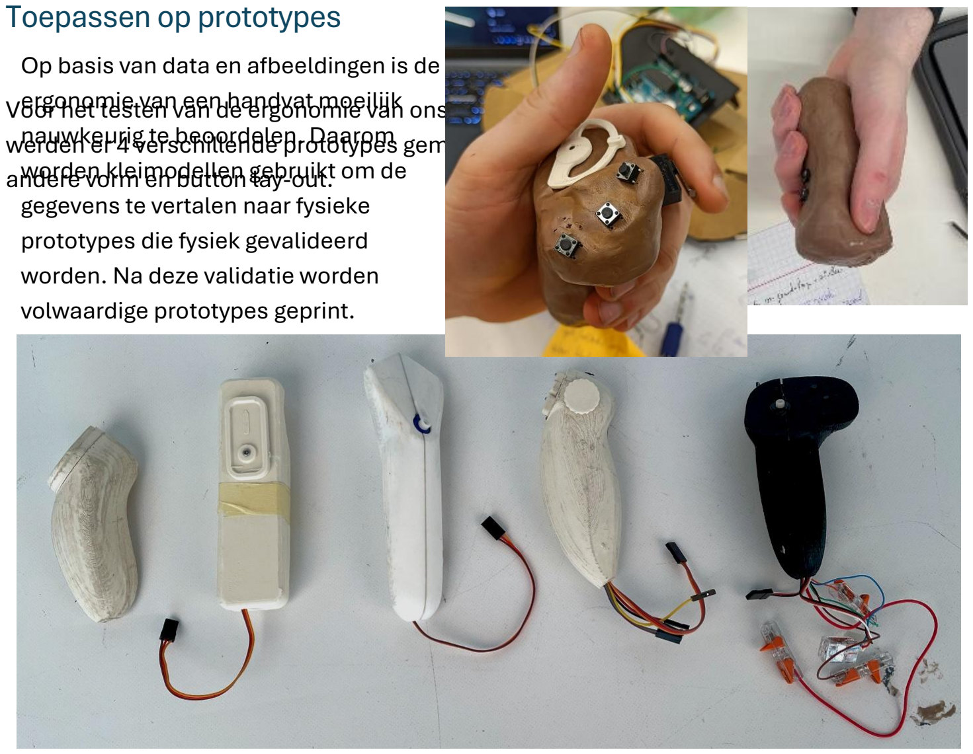
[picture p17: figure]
Toepassen op prototypes; andere vorm en button lay-out.; Op basis van data en afbeeldingen is de ergonomie van een handvat moeilijk nauwkeurig te beoordelen. Daarom worden kleimodellen gebruikt om de gegevens te vertalen naar fysieke prototypes die fysiek gevalideerd worden. Na deze validatie worden volwaardige prototypes geprint.

Voor het testen van de ergonomie van ons product bij de doelgroet werden er 4 verschillende prototypes gemaakt worden met elk een

Prototypes
Type 1:

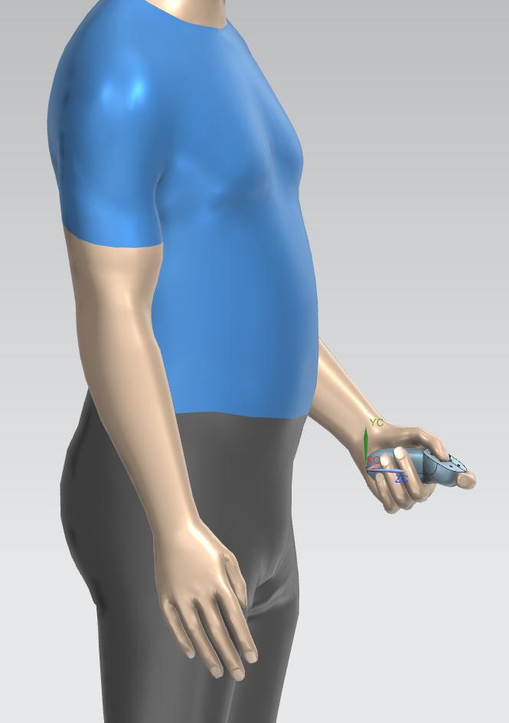
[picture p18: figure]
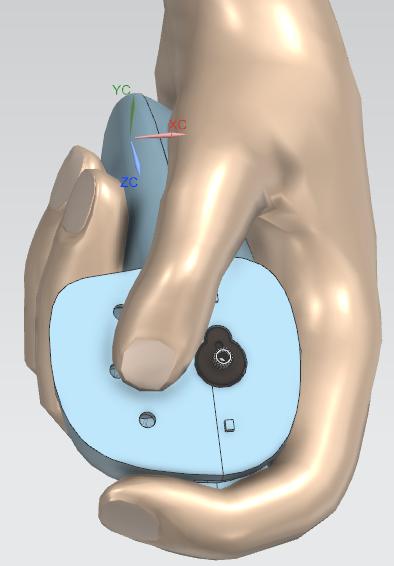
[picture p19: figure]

Deze versie van het product is sterk gebaseerd op een VR controller. Hierbij is plaats voorzien voor de richtingswijzer met daarnaast drie knoppen om het toestel te bedienen, aan de voorzijde is ook een trigger voorzien als extra input. De nominale maten werden toegepast bij het ontwerpen van deze versie.

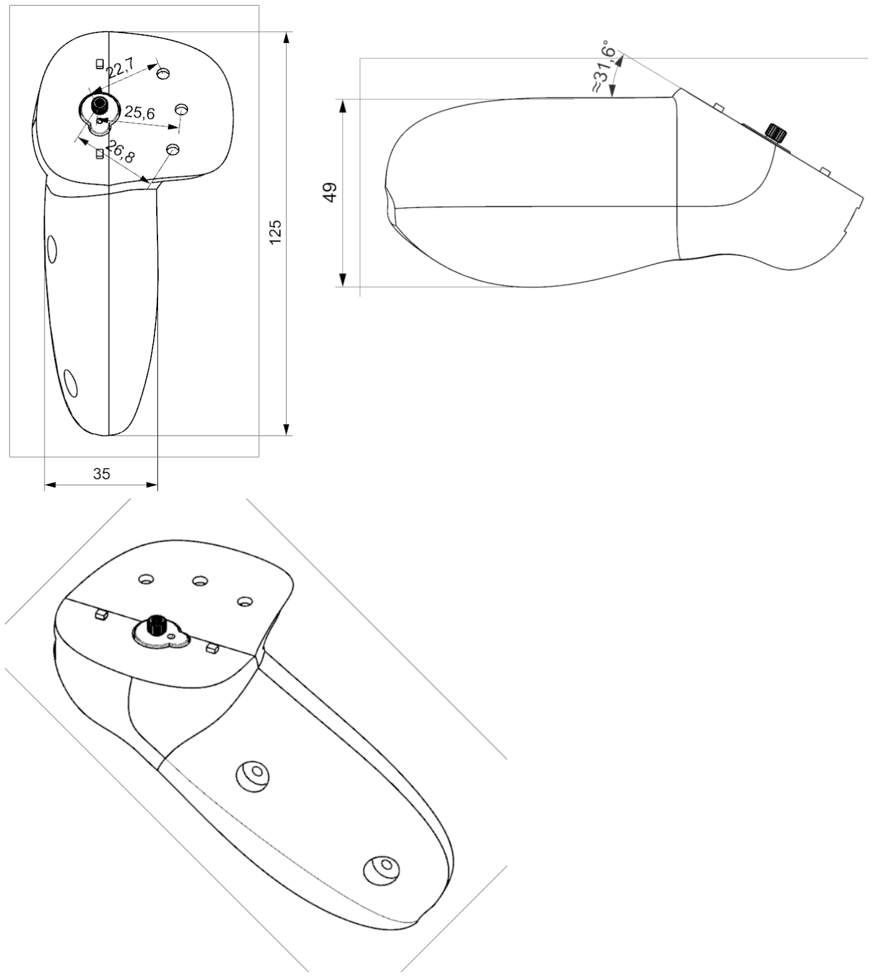
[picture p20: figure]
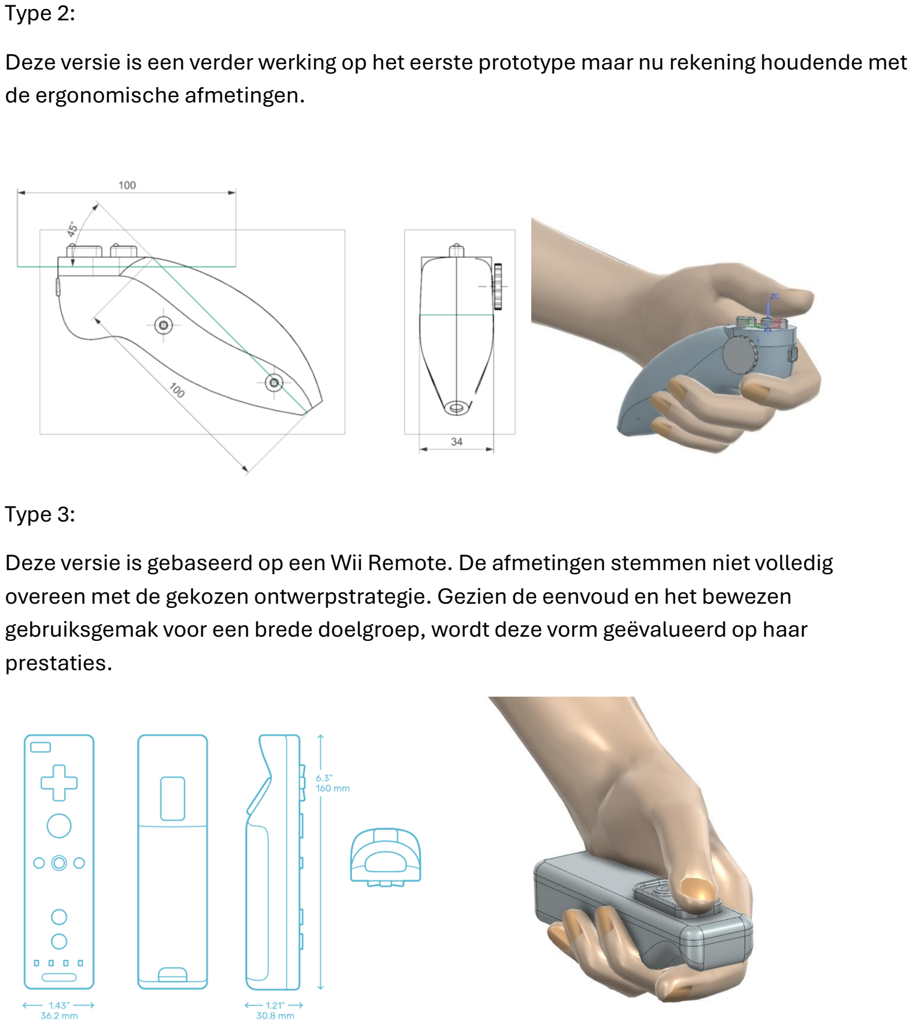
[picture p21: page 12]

Type 2:
Deze versie is een verder werking op het eerste prototype maar nu rekening houdende met de ergonomische afmetingen.

Type 3:
Deze versie is gebaseerd op een Wii Remote. De afmetingen stemmen niet volledig overeen met de gekozen ontwerpstrategie. Gezien de eenvoud en het bewezen gebruiksgemak voor een brede doelgroep, wordt deze vorm geëvalueerd op haar prestaties.

Type 4:

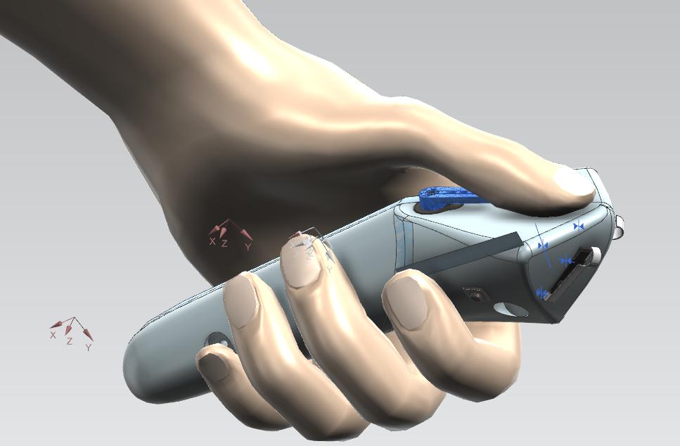
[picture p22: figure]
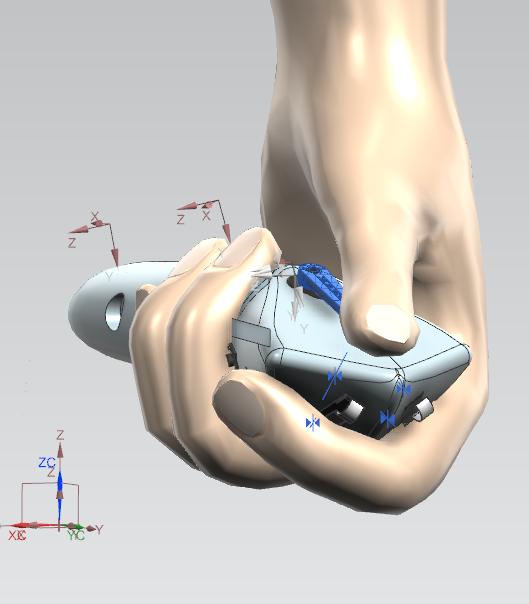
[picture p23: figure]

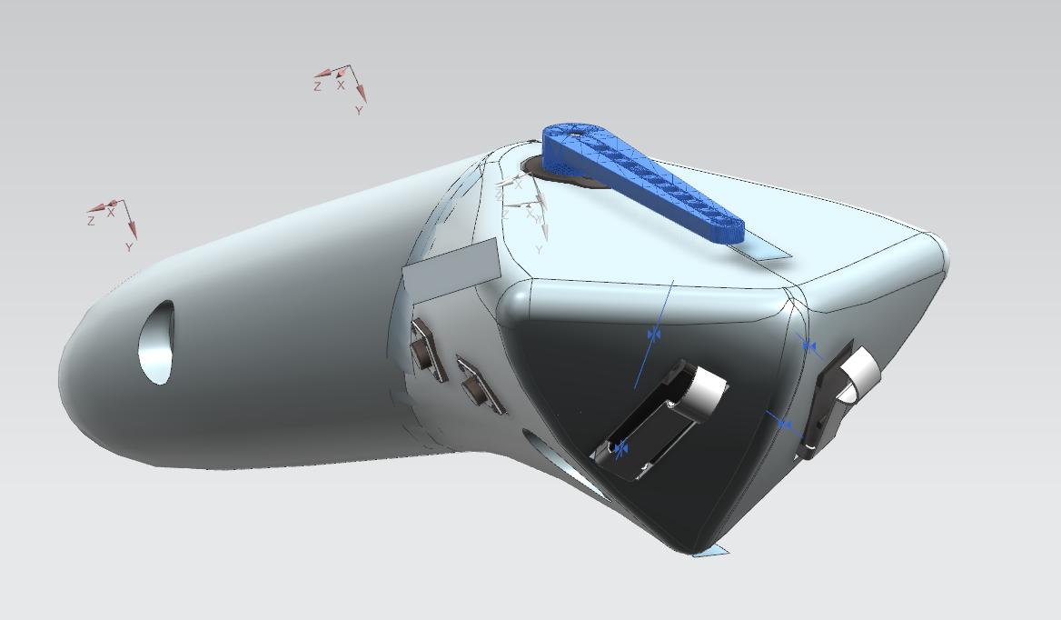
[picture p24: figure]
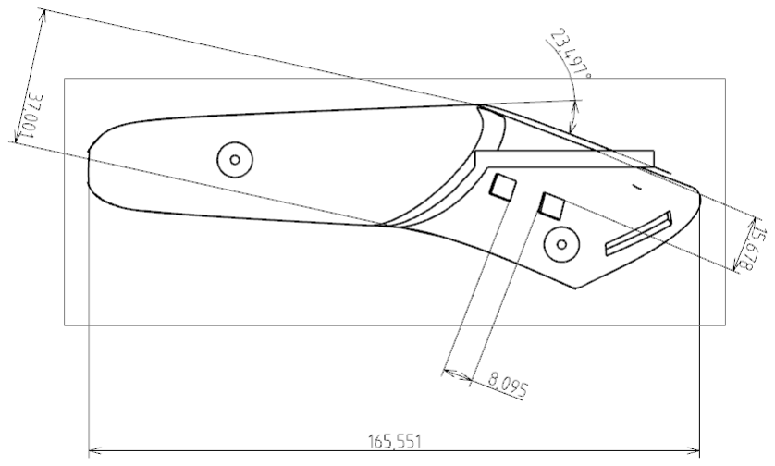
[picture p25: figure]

Het handvat van deze versie is gebaseerd op een Braun 7 series trimmer. De wijzer zit vanboven en is aangeduid op de foto door een blauwe kleur. Verder geeft het toestel vier knoppen 2 drukknoppen aan de rechterzijde en 2 triggers aan de voorkant. De nominale maten werden toegepast bij het ontwerpen van deze versie.

## Figurenlijst

Geen gegevens voor lijst met afbeeldingen gevonden.

## Bibliografie

DJI RC Motion 3 - Motion Control, Easy ACRO - DJI United States. (n.d.). DJI. https://www.dji.com/be/rc-motion-3

Wikipedia contributors. (2026, March 25). Meta Quest 3. Wikipedia. https://en.wikipedia.org/wiki/Meta_Quest_3

Genshin Impact Limited Edition DualSense Controller | PS5. (n.d.). [Video]. PlayStation.
https://www.playstation.com/en-hk/accessories/dualsense-wireless-controller/

Wikipedia contributors. (2026b, April 24). Wii Remote. Wikipedia. https://en.wikipedia.org/wiki/Wii_Remote

González, A. G. (2018). An ergonomic customized-tool handle design for precision tools using additive manufacturing: A case study. Applied Sciences. Opgehaald van doi.org: https://doi.org/10.3390/app8071200

Patkin's, M. (2026). A Check-List for Handle Design. (z.d.). Opgehaald van Michael Patkin's: https://mpatkin.org/ergonomics/handle_checklist.htm

Tilley, A. R. (1974). Opgehaald van Whitney Library of Design: https://arc104201516.wordpress.com/wp-content/uploads/2016/02/the-measure-of-man-and-woman-human-factors-in-design-alvin-r-tilley-henry

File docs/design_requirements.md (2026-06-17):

# SHERPA — Product Design Requirements

Elke requirement is opgesteld in de vorm 'Het systeem / De gebruiker [doet X]' en bevat een concreet meetcriterium met een pass/fail-grens. De prioriteit volgt de MoSCoW-methode. Het meettype geeft aan of getoetst wordt via directe observatie (Observed) of via bevraagde beleving (Perceived).

---

## 1 Gebruikers kunnen een traject zelfstandig afleggen zonder hulp van derden

| Nr. | Bron | Requirement | Meetcriterium (pass/fail) | Priority | Meting |
|-----|---|---|---|---|---|
| 1.1 | Develop 1 | Het systeem begeleidt de gebruiker doorheen een traject zodat elk herkenningspunt aantoonbaar bereikt wordt. | ≥ 100% van de herkenningspunten correct bereikt tijdens usability test (observatie per punt: ja/nee). | Must have | Observed |
| 1.2 | Definition wave 2 | Het systeem geeft eenduidige feedback bij correcte richting, foute richting, herkenningspunten en gevaarlijke locaties. | Deelnemer reageert correct (stopt, keert, bevestigt) op elk feedbacksignaal; ≥ 90% correcte reacties per sessie. | Must have | Observed |
| 1.3 | Definition wave 2 | De gebruiker toont geen verwarring bij de start van het traject. | Geen observeerbare verwarring (pauze > 10 s, foutieve richting, verbale twijfel) in de eerste 60 s; getoetst bij ≥ 4 van 5 deelnemers. | Should have | Observed |

---

## 2 Gebruikers kunnen met hulp van derden trajecten opnemen

| Nr. | Bron | Requirement | Meetcriterium (pass/fail) | Priority | Meting |
|-----|---|---|---|---|---|
| 2.1 | Definition wave 2 | De gebruiker kan met hulp van de begeleider persoonlijke herkenningspunten aanmaken. | Het duo slaagt erin om een herkenningspunt succesvol aan te maken; Ja/Nee. | Should have | Observed |
| 2.2 | Develop 2 | Een begeleider kan zonder technische voorkennis een traject aanmaken. | Opnametijd gemeten bij 2 begeleiders; beide trajecten klaar in ≤ 15 min. | Should have | Observed |
| 2.3 | Develop 2 | De begeleider ervaart het opnameproces als eenvoudig. | Likert 1–7 'Het opnemen van het traject was eenvoudig.' ≥ 5/7. | Could have | Perceived |

---

## 3 Gebruikers ervaren continu oriëntatie en vertrouwen tijdens het gebruik

| Nr. | Bron | Requirement | Meetcriterium (pass/fail) | Priority | Meting |
|-----|---|---|---|---|---|
| 3.1 | Definition wave 2 | Het systeem geeft continu de huidige looprichting visueel of tactiel weer. | Wijzer reageert op richtingsverandering van ≥ 15° binnen 0,5 s; getoetst via QAP-meting. | Must have | Observed |
| 3.2 | Develop 1 | De gebruiker ontvangt bevestiging (trilpatroon of wijzerpositie) wanneer hij correct georiënteerd staat. | Deelnemer herkent het bevestigingssignaal correct bij ≥ 4 van 5 pogingen (evaluatieblad). | Should have | Observed |
| 3.3 | Develop 1 | Het wijzersysteem heeft een duidelijk voelbaar nulpunt dat de neutrale (correcte) richting aangeeft. | Deelnemer wijst de richting aan binnen de sectoren van 30° bij ≥ 4 van 5 metingen (cirkeltest, sectordiagram). | Must have | Observed |
| 3.4 | Definition wave 2 | De gebruiker legt minder bekende trajecten af met zelfvertrouwen dankzij het systeem. | Likert 1–7 'Ik had er vertrouwen in dat ik de bestemming zou bereiken.' ≥ 5/7 gemiddeld. | Must have | Perceived |

---

## 4 Gebruikers blijven fysiek veilig tijdens navigatie

| Nr. | Bron | Requirement | Meetcriterium (pass/fail) | Priority | Meting |
|-----|---|---|---|---|---|
| 4.1 | Definition 1 | Het gebruik van de witte stok wordt niet belemmerd door het product. | Deelnemer raakt geen obstakel dat door de stok gedetecteerd had moeten worden; 0 obstakelcontacten bij ≥ 3 deelnemers tijdens trajecttest. | Must have | Observed |
| 4.2 | Definition 1 | Het product is volledig bedienbaar met één hand. | Alle interacties (opstart, navigatie, stop) worden uitgevoerd met één hand; 0 gevallen waarbij tweede hand nodig was (observatie). | Should have | Observed |
| 4.3 | Definition 1 | Het systeem geeft duidelijke feedback bij gevaarlijke locaties (zebrapad, open ruimte, tunnel). | Correct feedbacksignaal wordt gegeven op alle vooraf gedefinieerde gevaarlijke punten in het testparcours. | Must have | Observed |
| 4.4 | Evaluatie burgerlijk ing. | Het systeem detecteert wanneer GPS-signaal of sensorkoppeling wegvalt en signaleert dit aan de gebruiker. | Bij signaalverlies geeft het toestel direct een foutmelding (audio of trilpatroon). | Should have | Observed |
| 4.5 | Develop 1 | De gebruiker krijgt bevestigende feedback dat het systeem actief en correct werkt bij opstart. | Bevestigingssignaal (tril of audio) hoorbaar/voelbaar; herkend door ≥ 4 van 5 deelnemers. | Should have | Observed |
| 4.6 | Develop 1 | Het systeem houdt de gebruiker op een veilig pad met een nauwkeurigheid van ≤ 60 cm afwijking. | Steps-in-Zone (SIZ) ≥ 90% op een pad van 60 cm breedte; gemeten via video-observatie (identieke methode Develop 1/2). | Must have | Observed |
| 4.7 | Develop 2 | De batterijlevensduur is voldoende voor minstens 4 uur actief gebruik. | Toestel blijft actief gedurende een gesimuleerde sessie van 2 uur zonder laadonderbreking; getoetst via technische duurtest. | Must have | Observed |

---

## 5 Het systeem vereist minimale training en mentale en fysieke inspanning

| Nr. | Bron | Requirement | Meetcriterium (pass/fail) | Priority | Meting |
|-----|---|---|---|---|---|
| 5.1 | Discovery | De UI is volledig bedienbaar zonder visuele informatie (geschikt voor blinden en slechtzienden). | Blinde deelnemers voltooien alle UI-taken (opstart, trajectkeuze, stop) zonder blokkering bij ≥ 4 van 5 deelnemers. | Must have | Observed |
| 5.2 | Definition wave 1 | De bedieningsknoppen zijn tactiel onderscheidbaar (voelbare rand, hoogteverschil, index). | Deelnemer identificeert elke knop correct op gevoel zonder uitleg; ≥ 4 van 5 deelnemers slagen bij eerste aanraking. | Should have | Observed |
| 5.3 | Develop 1 | Trilsignalen bevatten maximaal 3 onderscheidbare patronen en brengen geen complexe data over. | Elk trilpatroon wordt door ≥ 100% van de deelnemers correct geïnterpreteerd; max. 3 patronen gedefinieerd in het systeem. | Must have | Observed |
| 5.4 | Develop 1 | Trilpatronen sluiten aan bij vertrouwde tactiele semantiek van blindengeleidetegels (kort=stop, lang=ga). | Likert 1–7 'De trilpatronen voelden vertrouwd aan.' ≥ 4,5/7 gemiddeld. | Should have | Perceived |
| 5.5 | Definition wave 1 | Het systeem is bruikbaar na een enkele uitlegsessie van ≤ 20 minuten. | Na een introductiefase van max. 20 min voltooit de deelnemer het testparcours met ≤ 2 begeleidersinterventies. | Should have | Observed |
| 5.6 | Develop 1 | De tactiele richtingaanwijzer bevindt zich op een positie die een neutrale, ontspannen polshouding toelaat. | ≥ 3 van 5 deelnemers nemen direct een neutrale polshouding aan bij eerste aanraking (observatie, geen aanwijzing). | Should have | Observed |
| 5.7 | Develop 2 | Het toestel past in een broekzak. | ≥ 4 van 5 deelnemers steekt het toestel zonder problemen weg. | Could have | Observed |
| 5.8 | Develop 1 | Het systeem ondersteunt elke essentiële stap (opstart, trajectkeuze, navigatie, herkenningspunt, stop) met gesproken instructie. | Alle essentiële stappen worden door het systeem ondersteund met gesproken instructie; gecontroleerd via walkthrough van het volledige parcours. | Must have | Observed |
| 5.9 | Develop 2 | De gebruiker heeft vertrouwen dat het toestel niet uit de hand kan vallen tijdens gebruik. | Minstens 90% van de gebruikers rapporteert een gevoel van zekerheid tijdens het vasthouden én geen enkele gebruiker laat het toestel vallen tijdens de gebruikstest. | Should have | Observed / Perceived |

---

## Legende

| Term | Betekenis |
|---|---|
| **Must have** | Kritieke vereiste; product faalt als dit niet gehaald wordt. |
| **Should have** | Belangrijke vereiste; sterk aanbevolen maar niet blokkerend. |
| **Could have** | Wenselijke extra; enkel als tijd en budget het toelaten. |
| **Observed** | Getoetst via directe observatie of video-analyse tijdens de test. |
| **Perceived** | Getoetst via Likert-schaal of gestructureerde bevraging na de test. |

> **Nummering:** is niet chronologisch, maar geplaatst bij de bijhorende productdoelstelling.

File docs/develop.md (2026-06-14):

# Develop 1 (N = 5)

In deze eerste ontwikkelingsfase wordt het concept vertaald naar een functionele architectuur. Door het product op te splitsen in verschillende deelaspecten ontstaat meer inzicht in hoe het systeem zal werken en welke onderdelen nodig zijn. Daarnaast worden testen uitgevoerd met de doelgroep om de onderzoeksvragen, gebaseerd op de design requirements, te beantwoorden.

## Architectuur

Het systeem wordt opgesplitst in twee grote onderdelen: de **recordfase** en de **playfase**. Voor beide fases werd een Minimum Viable Product (MVP) gedefinieerd.

### Recordfase

- Het toestel kan een traject opnemen terwijl de gebruiker het traject aanleert.
- Het traject kan worden opgeslagen.

### Playfase

- De gebruiker kan een opgeslagen traject ophalen.
- Het toestel begeleidt de gebruiker doorheen het traject.

Onderstaand schema toont de verschillende fases en hun onderlinge relaties.

<p align="center">
  
  <br>
  <em>Systeemarchitectuur en user flow van het systeem met record- en playfase.</em>
</p>

## Onderzoeksvragen

De onderzoeksvragen dienen om de design requirements te vertalen naar concrete productspecificaties.

| Requirement | Onderzoeksvraag |
|---|---|
| **D3.1** Het systeem geeft continu de huidige looprichting tactiel weer. | Wat betekent de studie van Liu et al. (2021) voor het concept? |
| **D3.4** De gebruiker legt minder bekende trajecten af met zelfvertrouwen dankzij het systeem. | Wat is er nodig zodat het wijzerconcept voldoende zekerheid biedt aan de gebruiker? |
| **D5.1** De UI is volledig bedienbaar zonder visuele informatie. | Welke elementen uit de systeemarchitectuur kunnen via trilsignalen worden gecommuniceerd? |

Drie deelonderzoeken werden uitgevoerd met vijf visueel beperkte respondenten, variërend van volledig blind tot personen met restvisus.

<p align="center">
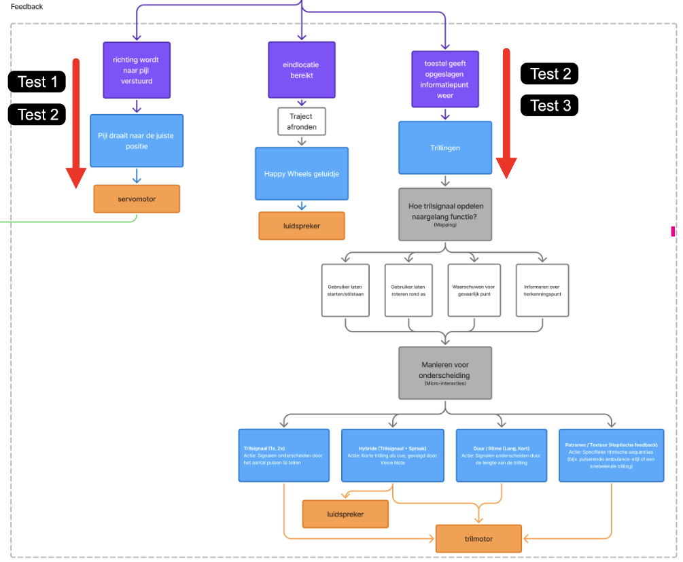
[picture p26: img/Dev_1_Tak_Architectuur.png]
  
  <br>
  <em>Bevinding van testen in de architectuur.</em>
</p>

## User Testing

Voor de testen werden een protocol en een rapport opgesteld.

- [Protocol](<../reports and protocols/protocol_Deelopdracht 3 develop 1.pdf>)
- [Rapport](<../reports and protocols/Verslag_Deelopdracht 3 develop 1.pdf>)

## Interactieve prototypes

Om Vanuit het prototype uit de vorige fase werden zes varianten ontwikkeld. Na een interne evaluatie werden deze herwerkt en samengevoegd tot een testopstelling die werd aangestuurd met een RC-controller.

<p align="center">
  
  <br>
  <em>Overzicht van de ontwikkelde develop 1 prototypes.</em>
</p>

## Test 1 – Cirkeltest

<p align="center">
  
  
  <br>
  <em>Cirkeltest in actie</em>
</p>

### Opzet

De proefpersonen stonden in het midden van een cirkel die was onderverdeeld in sectoren van 30°. Drie prototypes (driehoek, draaiwijzer en schijf met balk) werden draadloos aangestuurd. De gebruiker voelde de stand van de wijzer, draaide zich naar de vermeende richting en wees met een witte stok. De afwijking ten opzichte van de doelrichting werd geregistreerd.

### Resultaten

#### Referentie en positie

Bij versie C trad een omgekeerd effect op. De pijl wees naar links, terwijl de testpersoon naar rechts draaide. Drie van de vijf testpersonen interpreteerden de stilstaande pijl als richtingaanwijzer en het draaiende element als referentie.

Mark, die nog over restvisus beschikt, scoorde goed met versie C. Dit was de enige versie met voldoende visueel contrast.

Bij versie B werden bewegend element en referentiepunt omgewisseld. Dit leverde geen interpretatieproblemen op.

Bij versie A ontbrak een vast referentiepunt, wat resulteerde in minder nauwkeurige positionering.

#### Zelfzekerheid

Versie A gaf gebruikers het meeste vertrouwen, maar leidde tegelijk tot de meeste fouten. Een grotere pijl lijkt dus meer vertrouwen te creëren, ongeacht de daadwerkelijke nauwkeurigheid.

##### Belangrijkste bevindingen

- Een referentiepunt is noodzakelijk.
- Het referentiepunt bevindt zich best achter de pijl.
- Een grotere pijl wordt duidelijker ervaren.
- Extra contrast verhoogt de bruikbaarheid voor slechtzienden.

#### Evaluatie van de test

De cirkeltest leverde waardevolle inzichten op voor de leercurve en het gebruikersvertrouwen. De opstelling was echter niet nauwkeurig genoeg om harde uitspraken te doen over een richtingsnauwkeurigheid binnen 30°.

##### Beperkingen

- **Onderzoekersbias:** timing van metingen was niet altijd consistent.
- **Resolutie:** de positie van deelnemers kon niet altijd exact worden afgelezen.

---

## Test 2 – Trajectaanduiding

### Opzet

Met de twee best presterende prototypes (driehoek en draaiwijzer) werd een wandelparcours met rechte stukken en bochten afgelegd.

<p align="center">
  
  <br>
  <em>Wandelparcours met obstakels gebruikt in de trajectaanduidingstest.</em>
</p>

### Resultaten

- **Driehoek (3/5 voorkeur):** functioneerde goed, maar er was behoefte aan een duidelijk referentiepunt. Dit werd tijdens de test tijdelijk opgelost met tape.
- **Draaiwijzer (2/5 voorkeur):** werd intuïtief gebruikt, maar het onderscheid tussen het draaiende deel en het referentiepunt moet duidelijker worden aangegeven.
- **Houding:** 3 van de 5 deelnemers hielden het prototype correct vast. Twee deelnemers hielden het omgekeerd (met de pijl naar beneden gericht), wat wijst op de noodzaak van een meer ergonomische vormgeving.
- **Parkinson:** één respondent met Parkinson gebruikte haar wijsvinger om de pijl af te tasten in plaats van haar duim.
- **Richtingscorrecties:** kleine richtingsaanpassingen werden beter geïnterpreteerd dan grote richtingsveranderingen.

#### Opmerking van een deelnemer

> *"Kom maar eens mee naar het Citadelpark, dan vind ik misschien wel mijn weg terug."* — Chris

Deze uitspraak suggereert dat de deelnemer vertrouwen had in het toestel en de potentie ervan zag voor gebruik in een reële navigatiecontext.

---

## Test 3 – Vibratiefeedback

### Opzet

Tijdens de wandeling werden trilsignalen gegeven met vaste betekenissen (start, herkenningspunt, waarschuwing, stop). Reactietijd en interpretatiefouten werden genoteerd.

<p align="center">
  
  <br>
  <em>Overzicht van de gebruikte trilconventies tijdens de vibratiefeedbacktest.</em>
</p>

### Resultaten

- Lange trillingen voor start en stop werden correct geïnterpreteerd.
- Complexere patronen veroorzaakten verwarring en interpretatiefouten.

#### Belangrijkste bevinding

Complexere signalen vereisen bijkomende verduidelijking of training.

---

## Nieuwe Design Requirements

| ID | Design Requirement |
|---|---|
| D5.6 | De tactiele richtingaanwijzer bevindt zich op een locatie die een neutrale en ontspannen polshouding toelaat tijdens het wandelen. |
| D3.5 | Het toestel is accuraat genoeg om de gebruiker op een veilig pad te houden en te begeleiden naar herkenningspunten. |
| D3.2 | De gebruiker krijgt bevestiging wanneer hij correct georiënteerd is. |
| D3.3 | Het wijzersysteem bevat een duidelijk nulpunt of referentiepunt. |
| D5.4 | De trilpatronen volgen de bestaande en vertrouwde tactiele semantiek van blindengeleidetegels. |

---

# Develop 2 (N = 5)

## Inleiding

In deze fase worden zowel de ergonomie van de controller als de nodige knoppen en hun plaatsing op het product onderzocht.  
Op basis van vooronderzoek en bestaande studies werden verschillende prototypes ontwikkeld. Deze prototypes werden vervolgens getest bij de doelgroep.

---

## Onderzoeksvragen

De onderzoeksvragen zijn opnieuw gebaseerd op de design requirements:

| Requirement | Onderzoeksvraag |
|---|---|
| **D5.5** Het systeem is bruikbaar na een enkele uitlegsessie van ≤ 20 minuten. | Hoe maken we de interacties ergonomisch, met nadruk op een lage mentale belasting? |
| **D5.6** De tactiele richtingaanwijzer bevindt zich op een locatie die een neutrale en ontspannen polshouding toelaat tijdens het wandelen. | Hoe kan de vorm van het product de houding van de gebruiker sturen? |
| **D5.1** De UI is volledig bedienbaar zonder visuele informatie. | Welke knoppen zijn geschikt en bruikbaar voor de doelgroep? <br> Wat is de beste plaatsing van deze knoppen op het product? |

<p align="center">
  
  <br>
  <em>Bevinding van testen in de architectuur.</em>
</p>

---

## Vooronderzoek ergonomie en verloop

Om het ontwerpproces te ondersteunen, werden de prototypes gebaseerd op bestaande producten en onderzoek. Het volledige ergonomie onderzoek is hier te lezen: 

- [Ergonomie](<../reports and protocols/onderzoek_develop_2.pdf>)

### Aanpak

1. Analyse van bestaande producten (benchmark)
2. Mapping van noodzakelijke inputs naar button layouts
3. Onderzoek naar ergonomie van de hand
4. Bepalen van kritische maten
5. Vastleggen van afmetingen via ontwerpstrategie
6. Validatie via kleimodellen
7. Uitwerken van prototypes voor testing

---

## User Testing

De test bestaat uit twee delen die de interactie van de gebruiker met het toestel onderzoeken: een fysieke interactietest rond grip en houding, en een scenario-gebaseerde test waarbij de een deel van de gebruikersflow wordt nagebootst.

### Testopzet

- **Test 1:** In het eerste deel wordt de houding en greep van de gebruiker onderzocht. De testpersonen staan recht en krijgen verschillende prototypes één voor één aangereikt. Ze verkennen de grip intuïtief en rangschikken de prototypes vervolgens van minst naar meest comfortabel, waarbij ze hun keuze toelichten.

- **Test 2:** In het tweede deel wordt een realistisch gebruiksscenario nagebootst. Deelnemers krijgen eerst een korte briefing over het toestel en doorlopen daarna de volledige flow alsof ze op pad gaan: het toestel opbergen, zich voorbereiden met hulpmiddelen, het toestel activeren, een traject selecteren en starten. Dit loopt tot het moment waarop de gebruiker effectief “vertrekt”.

<p align="center">
  
  <br>
  <em>Develop 2 greep analyse.</em>
</p>

Voor de testen werden een protocol en rapport opgesteld:

- [Protocol](<../reports and protocols/protocol_develop_2.pdf>)
- [Rapport](<../reports and protocols/Rapport_develop_2.pdf>)

---

## Resultaten

### Grip en ergonomie
Prototypes 2 en 5 voldeden aan D5.6 door een duidelijke griporiëntatie. Prototype 2 werd soms omgekeerd vastgenomen, terwijl de asymmetrische versie (3) verwarring veroorzaakte en onvoldoende rekening hield met wisselend handgebruik.

Hoewel gebruikers vaak getraind zijn om de witte stok in de rechterhand te gebruiken, blijkt dit in de praktijk geen vaste regel: ze wisselen regelmatig van hand afhankelijk van de situatie.

#### Belangrijk inzicht
- Het toestel moet bruikbaar zijn voor zowel links- als rechtshandigen.

---

### Opbergen en draagbaarheid

Gebruikers plaatsen het toestel bij hun witte stock, deze staat meestal ergens aan de voordeur opgeborgen. Qua draagbaarheid is compactheid belangrijk; het past doorgaans in jaszak of handtas. De asymmetrische vorm van versie 3 verminderde de draagbaarheid en toonde aan dat niet alleen grootte, maar ook vorm bepalend is voor opbergen.

#### Belangrijk inzicht
- Gebruikers willen een compact toestel dat hen niet verhindert.
- Het toestel heeft de mogelijkheid om op een vaste plaats opgeslagen te worden.

---

### App vs. geïntegreerde interactie

- App werkt voor selectie, maar creëert onzekerheid na keuze.
- Gebruikers vergaten soms het toestel te activeren.

#### Belangrijk inzicht
- Wisselen tussen toestel verhoogt cognitieve belasting.

---

### Multitasking

- Combinatie van gsm + toestel + hulpmiddelen gaf problemen.
- Gebruikers verloren overzicht.

> *"Een deelnemer vroeg tijdens de test of we even het prototype wouden vasthouden terwijl zij haar ander gerief verzamelde"*.

#### Conclusie
- Voorkeur om alle interacties in een toestel te integreren.

---

### Interactie op het toestel

We zien duidelijk dat minder knoppen overeenkomen met minder fouten.  
Deze observatie sluit aan bij wet van Hick.

- Beste variant:
  - 1 aan/uit knop
  - 1 selectie/bevestiging knop

Deze voldoet aan **D5.1 en D5.2**.

#### Belangrijk inzicht
- Interactie moet lineair en volgtijdelijk zijn:
  1. Toestel aan
  2. Traject selecteren
  3. Traject starten

---

### Tactiele herkenbaarheid van knoppen

- Knoppen waren niet altijd direct herkenbaar.
- Soms werden andere onderdelen als knop geïnterpreteerd.

#### Conclusie
- Tactiele hiërarchie moet sterker worden.

---

### Rotary encoder

- Niet geschikt:
  - Te snel inputgedrag
  - Te groot
  - Haakt bij opbergen

---

### Perceived quality

Deelnemers gingen opmerkelijk voorzichtig om met de prototypes.

#### Conclusie
- Eindproduct moet robuust en kwalitatief aanvoelen.

## Nieuwe Design Requirements

| ID | Design Requirement |
|---|---|
| D3.4 | Het ontwerp communiceert visueel en tactiel een gevoel van stevigheid en duurzaamheid. |
| D5.7 | Het toestel past in een broekzak. |
| D5.8 | De gebruiker heeft vertrouwen dat het toestel niet uit de hand kan vallen tijdens gebruik. |

# Develop 3 (N = 2)

## Inleinding 
Dit is de eindfase van dit ontwerpproces. In deze fase wordt de CMF onderzocht en toegepast op het product. Daarnaast wordt ook kort eens gekeken naar de marktplaats van SHERPA en plaatsing binnen de maatschappij. Als laatste wordt ook nog een finale test uitgevoerd om te kijken hoe het product in de echte wereld presteert. Het tweede deel is een overkoepelende praktijktest waarbij het volledige systeem in een realistische omgeving wordt geëvalueerd.

- [Protocol Develop 3](<../reports and protocols/protocol_develop_3.pdf>)
- [Rapport Develop 3](<../reports and protocols/Rapport_develop_3.pdf>)

### Deel 1 CMF onderzoek 
Het voledige onderzoek is te lezen in het protocol en rapport van deze fase.

##### Doel van het onderzoek

CMF (Color, Material, Finish) en marktpositie: onderzoeken welke kleuren, materialen en afwerkingen het meest geschikt zijn en hoe potentiële gebruikers het product in de markt zien.

<p align="center">
  
  <br>
  <em>CMF refentieproducten.</em>
</p>

Voor het CMF-onderzoek kregen respondenten verschillende referentieproducten (zoals scheerapparaten, controllers en tandenborstels) in willekeurige volgorde in handen. Ze werden bevraagd over onder andere:

* comfort en grip
* materiaalgevoel
* herkenbaarheid van knoppen
* kleurcontrast
* geschiktheid voor langdurig gebruik
* Belangrijkste bevindingen

Uit de interviews kwamen de volgende conclusies naar voren:

Vormgeving: de vorm moet intuïtief aangeven hoe het product vastgehouden moet worden. De richting van de wijzer moet duidelijk zijn en knoppen moeten gemakkelijk voelbaar en herkenbaar zijn door reliëf of een afwijkende vorm.
Kleurgebruik: kleur moet een functionele rol spelen, bijvoorbeeld om knoppen beter zichtbaar te maken en het product gemakkelijker terug te vinden voor slechtziende gebruikers. Hoog contrast wordt als belangrijk beschouwd.
Materiaal: omdat het product buiten gebruikt wordt en schokken moet kunnen weerstaan, zijn sterke en impactbestendige materialen gewenst. Een combinatie van een harde kern met een rubberachtige buitenlaag werd door respondenten als comfortabel en praktisch ervaren.
Afwerking: een satijnen afwerking kreeg de voorkeur. Glossy oppervlakken werden als glad ervaren en matte oppervlakken zouden sneller vuil worden. Gladde knoppen werden positief beoordeeld.

##### Marktpositie en maatschappij

De respondenten zagen potentieel in SHERPA en zouden overwegen het te kopen als het een afgewerkt product was. Een mogelijke terugbetaling als medisch hulpmiddel zou de aantrekkelijkheid verhogen, terwijl een verplicht abonnement voor updates eerder negatief werd beoordeeld. Daarnaast kwam de vraag naar voren wie aansprakelijk is bij ongevallen tijdens het gebruik, dit vraagt verder juridisch onderzoek .

<p align="center">
  
  <br>
  <em>Stakeholderkaart </em>
</p>

**Producenten**
Profiteren van het terugbetalingssysteem voor erkende hulpmiddelen, wat hun marge vergroot en de drempel voor de gebruiker verlaagt.

**Oriëntatie- en mobiliteitstrainers**
Integreren het product in hun trainingsprogramma's en spelen een sleutelrol bij het opnemen van trajecten en de begeleiding op maat.

**Zorginstellingen**
Staan in voor verkoop, advies en nazorg. Als vertrouwd aanspreekpunt voor de doelgroep zijn zij een belangrijke schakel in de distributie.

**Begeleiders en mantelzorgers**
Ondersteunen de gebruiker bij het opnemen van trajecten en de dagelijkse werking van het systeem.

**Overheid**
Verantwoordelijk voor toegankelijke infrastructuur, maar in de praktijk zijn er nog veel tekortkomingen zoals ontbrekende geleidelijnen, slecht onderhouden voetpaden en inconsistent straatmeubilair. Betere infrastructuur vergroot de effectiviteit van SHERPA aanzienlijk.

---

###  Deel 2 - Overkoepelende test

### Testomgeving en setup

Twee trajecten werden geselecteerd op basis van situaties die tijdens de definitiefase door de deelnemers werden aangehaald. Beide bevatten uitdagingen die vaak voorkomen bij zelfstandig navigeren, zoals het oversteken van open ruimtes, het herkennen van oriëntatiepunten en het vinden van zebrapaden.

**Traject Dirk — Kortrijk**
Dirk gaf aan dat hij graag zelfstandig naar het zwembad zou gaan. Het traject tussen bushalte Kortrijk Weide en de ingang van het zwembad vormt een uitdaging door open ruimtes en zebrapaden. Herkenningspunten zijn onder andere paaltjes, een tunnelwand, goten en betonnen randen.

<p align="center">
  
  <br>
  <em>Traject Kortrijk Weide Lago</em>
</p>

**Traject Chris — Gullegem**
Chris beschreef een traject tussen Gent-Sint-Pieters en het MSK. Om praktische redenen werd een vergelijkbaar traject uitgewerkt in Gullegem, met herkenningspunten zoals stoepranden, riooldeksels, verlaagde boordstenen, grasranden en straatmeubilair.

---

### Prototype

Het werkende prototype bestond uit de volgende componenten:

- Een tactiele wegwijzer
- Een controledoos gedragen rond de nek
- Een webdashboard voor trajectmonitoring
- GPS-besturing met mogelijkheid tot manuele overname

Het systeem gaf trilsignalen bij het bereiken van herkenningspunten. Gesproken instructies werden tijdens de test door een begeleider gegeven.

<p align="center">
  
  <br>
  <em>Gebruikt prototype finale test</em>
</p>

---

### Testverloop

Voor beide trajecten werd hetzelfde scenario gevolgd:

1. De deelnemer wordt naar het startpunt gebracht.
2. Het prototype wordt aangebracht en kort toegelicht.
3. De deelnemer start het traject.
4. De wegwijzer geeft richtingsinformatie.
5. Op vooraf bepaalde herkenningspunten worden trilsignalen en gesproken instructies gegeven.
6. Observaties worden geregistreerd gedurende het volledige traject.

---

### Resultaten

#### Wegwijzing

Op het eerste traject werkte het GPS-prototype aanvankelijk goed en werden de eerste herkenningspunten aantoonbaar bereikt. Na verloop van tijd begon de GPS te driften, waardoor we overschakelden naar manuele besturing. Hiermee werden de overige herkenningspunten zonder problemen bereikt. Eén interventie was nog nodig ter hoogte van herkenningspunt 3, waar een auto de deelnemer afleiding veroorzaakte.

Bij de tweede test werkte de GPS van bij het begin niet correct en schakelden we onmiddellijk over naar manuele sturing. Het traject in Gullegem verliep vlotter door het grotere aantal volglijnen. De deelnemer concentreerde zich vooral op het toestel op stukken zonder volglijn.

#### Aangeleerde gewoontes

Deelnemers verkozen op momenten hun eigen intuïtie boven de aanwijzingen van de wijzer. Zo volgden ze de stoeprand in plaats van de instructie om rechtdoor te gaan, en lieten ze een herkenningspunt los toen de wijzer haaks op de stoeprand wees. Dit bevestigt dat het toestel de aangeleerde mobiliteitstechnieken — zoals volglijnen en herkenningspunten — moet ondersteunen en niet doorkruisen.

#### Spraakinstructies

Spraakinstructies gaven duidelijk het meeste vertrouwen, meer dan de wijzer alleen. Op stukken met een volgbare route werd de wijzer nauwelijks gebruikt. Tussen H5, H6 en H7, waar geen volglijn beschikbaar was, schakelde de deelnemer volledig over op het wijzersysteem. Hier was een korte aarzeling zichtbaar, waarna de deelnemer de aanwijzingen van het systeem volgde.

#### Trilsignalen

De trilsignalen waren moeilijk te observeren in hun effect. Ongeacht het signaal stopte de gebruiker steeds en wachtte op de gesproken instructie. Tijdens de debrief gaven deelnemers aan dat ze de aard van het signaal niet actief interpreteren — enkel de aanwezigheid ervan volstaat als attentietrigger. Dit suggereert dat één uniform attentiesignaal voldoende is.

#### Trajectvoorbereiding

De trajecten werden uitgestippeld op basis van Google Earth en lokale kennis. De GPS-problemen roepen de vraag op of het verschil tussen Google Earth en de werkelijke situatie ter plaatse hieraan bijdraagt. Het effectief afwandelen van een traject samen met een begeleider blijkt noodzakelijk om accurate en actuele trajecten op te bouwen.

#### Debrief

<p align="center">
  
  <br>
  <em>Debrief</em>
</p>

Een deelnemer gaf spontaan aan geïnteresseerd te zijn in het toestel voor dagelijks gebruik. Een andere deelnemer merkte op dat de wijzer soms onduidelijk bewoog, wat te wijten is aan inconsistente manuele besturing door de onderzoeker.

---

### Succes metrics

In welke mate zijn we erin geslaagd om de vooropgestelde succes metrics te halen? Hieronder een overzicht:

| ID | Requirement | Meetcriterium | Traject 1 (Dirk) | Traject 2 (Chris) | Resultaat |
|----|---|---|---|---|---|
| D1.1 | Het systeem begeleidt de gebruiker doorheen een traject zodat elk herkenningspunt aantoonbaar bereikt wordt. | ≥ 100% van de herkenningspunten correct bereikt (observatie per punt: ja/nee). | H2 en H3 niet bereikt | H1 t.e.m. H6 bereikt | ⚠️ Gedeeltelijk |
| D1.2 | Het systeem geeft eenduidige feedback bij correcte richting, foute richting, herkenningspunten en gevaarlijke locaties. | Deelnemer reageert correct op elk feedbacksignaal; ≥ 90% correcte reacties per sessie. | H1 t.e.m. H8 | H1 t.e.m. H6 | ✅ Voldaan |
| D1.3 | De gebruiker toont geen verwarring bij de start van het traject. | Geen observeerbare verwarring (pauze > 10 s, foutieve richting, verbale twijfel) in de eerste 60 s. | Geen verwarring bij start, wel later door aangeleerde gewoontes | Geen verwarring bij start, wel later door aangeleerde gewoontes | ⚠️ Gedeeltelijk |
| D4.1 | Het gebruik van de witte stok wordt niet belemmerd door het product. | 0 obstakelcontacten bij ≥ 3 deelnemers tijdens trajecttest. | ✅ Voldaan | ✅ Voldaan | ✅ Voldaan |
| D5.5 | Het systeem is bruikbaar na een enkele uitlegsessie van ≤ 20 minuten. | Deelnemer voltooit het parcours met ≤ 2 begeleidersinterventies na max. 20 min uitleg. | ❌ Niet voldaan | ✅ Voldaan | ⚠️ Gedeeltelijk |
| D3.4 | De gebruiker legt minder bekende trajecten af met zelfvertrouwen dankzij het systeem. | BERT: Onzeker ←1·2·3·4·5·6·7→ Zelfzeker — drempel: ≥ +2 t.o.v. score zonder toestel. | Zonder: 2 · Met: 5 · Verschil: +3 | Zonder: 4 · Met: 6 · Verschil: +2 | ✅ Voldaan |

### Samenvatting

De GPS-technologie bleek onvoldoende betrouwbaar voor beide trajecten: manuele besturing werkte telkens wel. Spraakinstructies zijn de sterkste vertrouwensgever, de wijzer wordt vooral ingezet waar geen volglijn beschikbaar is. Trilsignalen functioneren puur als attentietrigger en niet als informatiedrager, wat het gebruik van één uniform signaal rechtvaardigt. Voor toekomstige testen is trajectvoorbereiding ter plaatse, samen met een begeleider, een vereiste.

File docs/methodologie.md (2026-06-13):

# Methodologie

Dit project volgt de principes van Human-Centered Design binnen het Triple Diamond-model. We doorliepen een iteratief proces, waarbij we via specifieke onderzoeksmethoden continu hebben samengewerkt met de visueel beperkte doelgroep.

<p align="center">
  SHERPA Methodologie Tijdlijn
</p>

**Discover: Problem Finding**
Om de leefwereld en navigatienoden van de doelgroep te doorgronden, combineerden we kwantitatieve en kwalitatieve methoden. We voerden literatuurstudies en benchmarking uit (N=16). Dit vulden we aan met etnografisch veldonderzoek (observaties op de Brailletech-beurs en bij een oogatelier) en diepgaande user interviews (N=3). Dit leidde tot de centrale **How Might We-vraag**: 
> *“Hoe kunnen we blinde personen ondersteunen bij het aanleren en onderhouden van trajecten?”*

**Define: Designing the Right Thing**
De ontwerpfase verliep via twee iteratieve *waves*:
* **Wave 1:** We bouwden low-fidelity prototypes van een tactiele pin-matrix. Via *concept testing* (N=2) en *usability testing* (N=6) in outdoormilieus evalueerden we de cognitieve belasting.
* **Wave 2 (Pivot):** Omdat de matrix te complex bleek, maakten we een cruciale pivot naar een fysiek draaibare pijl. Dit concept werd gevalideerd via *Wizard of Oz-testing* (N=2). Via een *weighted decision matrix* kozen we definitief voor dit concept en legden we de functionele eisen vast in een Product Requirement Document (PRD).

**Develop: Iterative Build Cycles**
Het concept werd doorontwikkeld in drie sprints:
* **Develop 1 (N=5):** De tactiele interactie werd geëvalueerd via gerichte *Wizard of Oz-testing*: *cirkeltesten* (richtingsnauwkeurigheid van zes pijlvarianten), *wandeltesten* met obstakels, en *vibratietesten* om haptische signalen af te stemmen.
* **Develop 2 (N=2):** De fysieke ergonomie werd iteratief vormgegeven via antropometrische data en benchmarks (N=11) van eenhandige controllers. Met fysieke kleimodellen en *scenario-testing* valideerden we de grip en button-layout voor gebruik naast de witte stok. De resultaten werden via *variety prototyping* vertaald naar 5 werkende prototypes.
* **Develop 3 (N=2):** De focus verschoof naar CMF en UX Excellence. Via benchmarking (N=9) van bestaande producten voor slechtzienden ontwierpen we de CMF-stragtegie van het product. Vervolgens werden de elektronica van project Opkomende Technologie geïntegreerd in de nieuwe behuizing, wat resulteerde in een autonoom en functioneel prototype.

**Deliver: Finaal Systeem & Validatie**
Tijdens outdoor *usability tests* (N=2) met het autonome, 3D-geprinte prototype valideerden we via directe observatie of de prioritaire eisen (vastgelegd via de *MoSCoW-methode* in het PRD) effectief werden behaald. Tot slot is het functionele eindresultaat, inclusief de werking in een realistische context, visueel vastgelegd in een wervend promotiefilmpje ter presentatie van het project.

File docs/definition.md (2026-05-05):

## Definition

# Iteratie 1 
### Doestellingen

In deelopdracht 2 (Definition Phase) zijn eerste low-fidelity prototypes ontwikkeld. Het doel was te onderzoeken of het concept van een tactiele kaart als ruimtelijk referentiekader begrijpelijk, bruikbaar en zinvol is voor mensen met een visuele beperking. De focus lag expliciet op “Design the Right Thing” vóór technologische verfijning.

Onderzoeksvragen:

- Hoe verkennen en interpreteren gebruikers tactiele kaartinformatie?

- Hoe leesbaar en resoluut zijn de kaarten?

- Welke functies maken het product bruikbaar (bijv. inzoomen, geluid instellen, bewegen met de kaart)?

- Welke interactiemethoden en draagwijzen zijn geschikt?

De werking is als volgt:

<p align="center">
  
</p>

### Materiaal & methoden
De eerste wave bouwen we op uit meerdere kleine testen waarmee we onze deelvragen beantwoorden. Hierna testen we het totaal concept.

#### 1. Orientatie N = 10

Het onderzoek onderzocht hoe gebruikers navigeren met tactiele kaarten. Tien geblinddoekte jongeren zonder visuele beperking legden een parcours af met een tactiele LEGO-kaart en/of verbale instructies. Twee groepen werden vergeleken: kaart + instructies versus alleen instructies, waarbij gedrag en tijd werden geregistreerd.

<p align="center">
  
</p>

#### 2. Kaart afmetingen N = 2

We onderzochten welke kaartresolutie het best tactiel waarneembaar is. Testpersonen verkenden meerdere kaarten met hetzelfde patroon maar verschillende resoluties en beschrijven wat ze voelden. Omdat alle kaarten hetzelfde patroon bevatten, lag de focus op de subjectieve ervaring: welke kaart voelde het duidelijkst en meest leesbaar aan? De test werd uitgevoerd met twee blinden.

<p align="center">
  
</p>

#### 3. Draagwijzen N = 6 

Blinden en slecht zienden lopen bijna altijd met de stok rond hierdoor is er dus nog maar een van hun handen vrij wanneer ze op stap gaan. Daardoor willen we testen op welke manier het product kan gedragen worden. Hiervoor hebben we drie opstellingen: het product los in de ene hand , het product bevestigd aan de arm met behulp van een brace, het product met daaraan een lanyard voor rond de nek te draggen.
<p align="center">
  
</p>
<p align="center">
  
</p>
De testpersonen kregen elk individueel alle verschillende opstellingen in de hand en mochten daarmee dan ook rondlopen. De meningen van iedereen werden ook in groep besproken.

#### 4. interactiemethoden N = 6 

Het product moet natuurlijk te besturen zijn , hiervoor zijn dan ook verschillende inputs voor nodig. Voor dit te testen werd gebruikgemaakt van een adaptief prototype met velcro waar verschillende soorten knoppen, draaiwielen, sliders en joysticks aan bevestigd kunnen worden.
<p align="center">
  
</p>
Deze kunnen dan georiënteerd worden zoals de gebruiker ze het liefst wilt.

<p align="center">
  
</p>

#### 5. Concept validatie N = 2 

Deelnemers legden een vooraf uitgestippeld traject af met opeenvolgende tactiele kaarten, elk met een begin- en eindpunt. Bij aankomst ontvingen ze een nieuwe kaart en gebruikten de think-aloud-methode tijdens interpretatie. Kaarten waren noordgericht, met GPS-feedback, en interventies bij fouten of veiligheidsrisico’s werden direct toegelicht. Zo werd geëvalueerd hoe goed deelnemers hun omgeving begrijpen via de kaarten.

<p align="center">
  
</p>
<p align="center">
  
</p>
<p align="center">
  
</p>

### Resultaten

Bij het testen van het totaalconcept kwamen meerdere fundamentele problemen naar voren. Gebruikers konden het traject interpreteren, maar een globale richtingsaanduiding alleen was onvoldoende voor zelfverzekerd navigeren. De complexiteit van de echte omgeving overstijgt de vereenvoudigde kaartweergave, waardoor cruciale context ontbreekt tijdens het wandelen.

Belangrijkste bevindingen:

- Een top-down Google Maps-achtige weergave is niet intuïtief voor blinde gebruikers.

- Effectieve oriëntatie vereist een dynamische, meedraaiende kaart met een duidelijk referentiepunt.

- Routeplanning is mogelijk, maar vraagt extra, duidelijk onderscheidbare feedback.

- Schaal, obstakels en hoogte-informatie bepalen de bruikbaarheid van de kaart.

- De kaart ondersteunt het initiële beslismoment, maar biedt onvoldoende begeleiding tijdens de voortbeweging.

Design Requirements:

- D1.4 Orientatie/richting van de route weergeven
- D2.2 Cognitieve belasting moet zo laag mogelijk zijn
- D2.3 bruikbaar na een uitlegsessie 
- D2.6 De bedieningsknoppen moeten een voelbare range hebben
- D2.8 Het product moet met 1 hand bruikbaar zijn
- D2.9 Contrast en kleur aanpasbaar aan voorkeur van gebruiker
- D4.1 Het product moet het zelfvertrouwen van de gebruiker versterken

### Conclusies & implicaties

De pinmatrix blijkt cognitief belastend en verwarrend. Gebruikers kunnen globale route-informatie afleiden, zoals rechtdoor, links of rechts, maar na zo’n beslismoment ontbreekt continuïteit en context om verder te navigeren. Het verkleinen van de schaal maakt de kaart te abstract en moeilijk bruikbaar.

In essentie blijft er een pijl over die een richting aangeeft.
Hiernaast willen we nog eens dieper ingaan op wat een blinde nodig heeft om comfortabel en zelfzeker een route te bewandelen. Dit bekijken we in iteratie 2.

# Iteratie 2
In deze wave willen we volgend concept onderzoeken:

<p align="center">
  
</p>

Hierbij willen we ook antwoord op volgende vragen:
1.	Welke informatie is daadwerkelijk nodig om blinden en slechtzienden comfortabel en met vertrouwen te begeleiden tijdens het navigeren?
2.	In welke situaties en mentale toestanden zou een blinde gebruiker dit product effectief willen gebruiken? 
3.	Is het mogelijk om blinden en slechtzienden effectief te sturen door uitsluitend (of voornamelijk) richting aan te geven met een pijl, en zo ja, onder welke voorwaarden

### Materiaal & methoden N = 2 
We doen dit aan de hand van enkele interviews gevolgt door usability testing.
Tijdens de interviews gaan we nog eens dieper in op de noden van de gebruikers en wanneer zo een toestel handig zou zijn. 

Bijkoment gaan we op wandel om een simpel pijlprototype te analyseren. Voor deze fase hebben we twee blinden en een begeleidster geraadpleegt.

<p align="center">
  
</p>

<p align="center">
  
</p>

### resultaten

Navigatie hangt af van zelfvertrouwen, herkenningspunten, herhaling en begeleiding. Voor blinden zijn een witte stok en een gsm voor noodgevallen essentieel.

Er is grote diversiteit binnen de blinde gemeenschap: sommige mensen zijn zelfstandig, terwijl anderen zonder begeleiding nauwelijks durven bewegen. Voor hen kan het wegwijzerconcept houvast en actieve ondersteuning bieden. Zelfzekere gebruikers hebben eerder baat bij hulpmiddelen die waarschuwen bij uitzonderingssituaties. Het pinmatrixconcept is vooral geschikt voor thuisgebruik, waar routes vooraf verkend en ingeoefend kunnen worden, zonder beperkingen qua omvang of draagbaarheid.

Design Requirements:

- D1.5 Verwarring bij start  van traject vermijden
- D1.6 Gebruiker kan zijn eigen herkennigspunten maken
- D5.3 Compatibel met IOS

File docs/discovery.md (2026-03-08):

## Discovery
Max. 1000 woorden.   
[!] Algmeen: Maak voldoende gebruik van schematische/grafische weergaves en tabellen.
### Doestellingen
Het doel van de discoveryfase was om inzicht te verkrijgen in de leefwereld van blinde en slechtziende personen. Met als focus hun dagelijkse leven en uitdagingen ontdekken. Uitendelijk willen we uit deze inzichten een "how might we" vraag opstellen. 

### Materiaal & methoden
Tijdens de discorvey fase gebruiken we verschillende kwalitatieve onderzoeksmethoden. We voerden interviews, benchmarks en een literatuur studie uit.

Wat de meest uitdagende taak bleek was het rondsellen van respondenten. Gelukkig was er toevallig in die periode een beurs.
<style>
img {
  float: right;
  border: 4px solid white;
  margin: 0px 0px 15px 20px;
}
</style>

<p float: right>
  
</p>

We  bezochten de jaarlijkse Brailletech-beurs. Tijdens deze beurs werden de nieuwste hulpmiddelen voor blinde en slechtziende gebruikers voorgesteld. De beurs bood een waardevolle gelegenheid om:

- in contact te komen met blinde en slechtziende bezoekers;
- te spreken met experts en ontwikkelaars van hulpmiddelen (zoals Sensotec);
- inzicht te krijgen in bestaande technologieën en ondersteuningsinitiatieven.

Daarnaast kwamen we via vrienden en familie in contact met een bereidwillige slechtziende persoon die openstond om ons verder te ondersteunen tijdens het project.

Ook bezochten we het oogatelier van Licht en Liefde in Kortrijk, een ontmoetingsplaats voor blinde en slechtziende personen. Hier konden we ook terecht om mensen te interviewen.

#### Interviews
we gingen elk appart op stap om respondenten te interviewen. Daarvoor maakten we elk ons eigen protecol en rapport.
De protocol van de interviews zijn hier te lezen: 

 [- Lander: Protocol interviews](<../reports and protocols/Protocol Interviews.pdf>)

 [- Roland: Protocol interviews](<../reports and protocols/Interviewprotocol_slechtzienden_!.pdf>)

 [- Corbin: Protocol interviews](<../reports and protocols/Interview-protocol-Corbin_Braekevelt.pdf>)

De rapports zijn hier te lezen: 

[- Lander: Rapport interviews](<../reports and protocols/Rapport Interviews.pdf>)

[- Roland: Rapport interviews](<../reports and protocols/Analyse respondenten rapport.pdf>)

[- Corbin: Rapport interviews](<../reports and protocols/Interview-raport-Corbin_Braekevelt.pdf>)

De interviews waren breed opgezet en behandelde verschillende thema's, waaronder mobiliteit, communicatie, sociale media, vrije tijd, hobby's en veiligheid. Op basis van deze verkennende gesprekken besloten we ons verder te focussen op mobiliteit, en meer specifiek op navigatie.

Met een focus op navigatie zijn we naar de braillebeurs getrokken.

#### Benchmarks en literatuurstudie

Protocollen van de literatuurstudies: 
Naast de interviews voerden we ook benchmarks en literatuurstudies uit naar bestaande hulpmiddelen en technologieën, om een breder beeld te krijgen van het huidige aanbod en de bestaande oplossingen. 
Hiervoor werden ook protocollen en raporten voor opgesteld:

[- Lander: Protocol literatuurstudie](<../reports and protocols/Protocol Literatuur Studie.pdf>)

[- Roland: Protocol benchmarking](<../>)

[- Corbin: Protocol benchmarking](<../reports and protocols/benchmarking_protocol_corbin_braekevelt.pdf>)

[- Lander: Rapport literatuurstudie](<../reports and protocols/Rapport Literatuur Studie.pdf>)

[- Roland: Rapport benchmarking](<../reports and protocols/Competitor analysis.pdf>)

[- Corbin: Rapport benchmarking](<../reports and protocols/benchmarking_raport_corbin_braekevelt.pdf>)

### Resultaten

#### Inzichten uit de interviews en observaties:

Er werden verschillende interviews afgenomen met blinde en slechtziende personen, aangevuld met informele gesprekken met organisaties en bedrijven op de Brailletech-beurs. Het doel was inzicht te krijgen in hun leefwereld, met een specifieke focus op mobiliteit en navigatie. Ondanks verschillen in leeftijd en context kwamen in alle gesprekken gelijkaardige patronen naar voren.

Een centraal inzicht is dat zelfstandige mobiliteit voor blinde personen sterk steunt op aangeleerde trajecten. Routes worden bewust voorbereid, ingeoefend en onderhouden, vaak met ondersteuning van een vertrouwd persoon. Onvoorspelbare factoren zoals wegenwerken, foutieve of slecht onderhouden infrastructuur en drukke stedelijke omgevingen zorgen voor onzekerheid en frustratie. Navigeren in binnenruimtes, zoals openbare gebouwen, blijkt daarbij vaak moeilijker dan buiten.

Digitale hulpmiddelen zoals gps-apps en smartphones worden gebruikt, maar blijken niet altijd betrouwbaar of praktisch in gebruik. Betrouwbaarheid en accuraatheid zijn essentieel,twijfel tijdens het navigeren wordt als onaanvaardbaar ervaren. Daarnaast blijkt gezelschap een belangrijke rol te spelen in het gevoel van veiligheid en vertrouwen.

Belangrijkste bevindingen:

- Sterke afhankelijkheid van aangeleerde trajecten

- Grote impact van infrastructuur en onderhoud

- Beperkingen van bestaande digitale hulpmiddelen

- Betrouwbaarheid van hulpmiddelen is essentieel

- Cruciale rol van vertrouwen, veiligheid en gezelschap

#### Inzichten uit de literatuur studie:

De geraadpleegde literatuur toont aan dat blinde personen effectief ondersteund kunnen worden door verschillende technologieën die tastzin, gehoor en beweging gebruiken of combineren. Hoewel traditionele hulpmiddelen zoals de witte stok en oriëntatietrainingen essentieel blijven, wijst onderzoek op een aanzienlijk potentieel van tactiele en haptische feedbacksystemen. Daarnaast tonen verschillende studies aan dat het gebruik van braillekaarten het oriëntatievermogen versterkt en bijdraagt aan het opbouwen van mentale kaarten van de omgeving.

Een terugkerend aandachtspunt in de literatuur is dat hulpmiddelen eenvoudig, betrouwbaar en gebruiksvriendelijk moeten blijven. Daarnaast benadrukken meerdere studies het belang van co-creatie: oplossingen die ontwikkeld worden in nauwe samenwerking met de doelgroep sluiten beter aan bij reële noden.

Opvallend is dat veel technologische oplossingen voornamelijk getest worden in gecontroleerde of gesimuleerde omgevingen. De overgang naar complexe, onvoorspelbare real-life contexten blijkt daarbij vaak een struikelblok, waardoor het product uitendelijk faalt.

### Conclusies & implicaties

Een van de belangrijkste bevindingen uit dit onderzoek is dat veel slechtzienden personen, en blinde gebruikers, sterk steunen op aangeleerde trajecten. Zelfstandige verplaatsing is voor hen mogelijk zolang een route vooraf zorgvuldig wordt aangeleerd en door regelmatige herhaling wordt onderhouden.

Dit inzicht werd onder meer geïllustreerd door het verhaal van Pieter-Jan, die volledig blind is. <em>Hij gaf aan dat hij samen met zijn slechtziende vrouw routes uitstippelt in hun thuisstad Antwerpen.</em> Dit voorbeeld toont aan dat zelfstandige mobiliteit niet spontaan ontstaat, maar het resultaat is van bewuste voorbereiding, herhaling en externe ondersteuning.

Op basis van dit inzicht creeëren we De "How Might We" vraag:
>'Hoe kunnen we blinde personen ondersteunen bij het aanleren en onderhouden van trajecten?'

<p align="center">
  
</p>

Als eerste conceptuele richting ontstond het idee van een tactiel navigatiesysteem, een soort van "tactiele gps". Met dit concept starten we de definitie fase.

Design Requirements:
- D1.1 aangeleerde trajecten onderhouden
- D1.2 Nieuwe trajecten aanleren
- D2.7 Docking station waar het product kan laden en een vaste plaats heeft
- D2.4 UI geschikt voor blinden en slechtzienden

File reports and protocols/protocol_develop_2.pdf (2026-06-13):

# Sherpa develop 2 protocol

Dit document bevat het protocol voor develop 2 en bestaat uit 2 testen.
De eerste test focust op comfort en ergonomie. De tweede op de interacties tussen de gebruiker en het toestel.
Respondenten:
Oogatelier | N=3 | 06/03/2026
Dirk | N=1 | 10/04/2026
Chris | N=1 | 08/04/2026

## Onderzoeksvragen

- Houding en greep van de gebruiker

Eerdere tests tonen dat verschillende grepen invloed hebben op het polscomfort. Daarom ligt de focus op een ergonomisch ontwerp dat een correcte greep stimuleert en de belasting op hand en pols minimaliseert.

- Hoe kan de vorm van het product de houding van de gebruiker sturen naar een comfortabele en ergonomische houding?
- Interactie tussen toestel en gebruiker

Het product bevat verschillende functies. De gebruiker moet hiermee interageren. Specifiek wordt ingegaan op hoe men het toestel in werking stelt, een traject selecteert, start en stopt. Met als vraag:

- Hoe maken we de interacties ergonomisch met nadruk op een lage mentale belasting?
- Positie van de knoppen op product

Gekoppeld aan de interactie wordt gekeken naar de positie van de input. Zowel de technische haalbaarheid als een aangename gebruikerservaring staan centraal.

- Wat is de beste plaatsing van de knopen op het product voor de doelgroep?

## Deel 1 Houding en greep van de gebruiker

Testomgeving en Setup
De test wordt uitgevoerd binnen aan een tafel. Zodanig dat wisselen tussen versies vlot verloopt. De testpersonen worden gevraagd om recht te staan zodat ze het toestel vasthouden op dezelfde wijze als wanneer ze wandelen.
Variabelen (De Prototypes)
Op basis van antropometrisch onderzoek, een kleimodelleer sessie en een benchmark werden 4 prototypes uitgewerkt. Een protype uit de eerste fase wordt ook geevalueerd.


Verloop van de Test
Eerst wordt het concept van het product uitgelegd aan de testpersonen Daarna krijgen ze een voor een de verschillende prototypes voorgeschoteld.
Hierbij observeren we hoe de persoon de greep verkend en welke greep er van nature toegepast wordt.
Na de testpersoon alle versies heeft gevoelt vragen we hen om ze van minst comfortabel naar meest comfortabel te rangschikken. Waarbij ze hun rangorde moeten verduidelijken. Taakverdeling en regels
- Persoon 1 (Begeleider): Geeft de verschillende prototypes aan de testpersonen, observeert en stelt vragen.
- Persoon 2 (observeerder): Observeert en neemt foto’s Dataverzameling
Kwalitatieve data
- Welke opmerkingen maken de person uit zichzelf?

Waarom vinden mensen sommige versies beter dan andere?
Kwantitatieve data
D5.2 | De bedieningsknoppen zijn tactiel onderscheidbaar (voelbare rand, hoogteverschil, index). | Deelnemer identificeert elke knop correct op gevoel zonder uitleg; ≥ 4 van 5 deelnemers slagen bij eerste aanraking.
D5.6 | De tactiele richtingaanwijzer is zo ontwerpen dat het een neutrale, ontspannen polshouding toelaat. | ≥ 4 van 5 deelnemers nemen direct een neutrale polshouding aan bij eerste aanraking (observatie, geen aanwijzing).
- Wat is de rangorde van de prototypes? Materiaal
- Prototypes
- Evaluatieblad
- Notitie gerief
- Camera

## Deel 2 Interactie tussen gebruiker en toestel

In dit deel zoemen we in op het opstart gedeelte van de architectuur en hoe een traject wordt opgehaald en gestart. We kijken naar op welke wijze de gebruiker deze acties uitvoert en hoe de interacties vertalen naar fysieke componenten.
Waarbij de hoofdvragen als volgt zijn
- Hoe maken we de interacties ergonomisch met nadruk op een lage mentale belasting?
- Wat is de beste plaatsing van de knopen op het product voor de doelgroep?


Opstart | Traject ophalen

Testomgeving en Setup
We spel de interactie zo realistisch mogelijk na. De opdracht is om met het toestel een wandeling te maken. Het scenario loopt tot de testpersoon uit de deur is en het traject heeft gestart. De persoon wordt gebrieft hoe het toestel werkt.
Naast de hoofdvragen zijn er een heleboel interessante observaties te maken.
- Gebruikers moeten het toestel leggen op een plaats waar ze het zouden opslaan (Waar?)
- Gebruikers maken zich zogezegd klaar om op stap te gaan. Hierbij nemen ze hun hulpmiddelen zoals een witte stock (Handen te kort?)
- Zetten zelfstandig het toestel en werking (Interactie onthouden en duidelijk?)
- Gebruiker selecteert een traject (Interactie onthouden en duidelijk?)
- Toestel in rusthouding (polsbandje)
- Start een traject (wanneer doen ze dit?)
Variabelen (De Prototypes)


In het schema zijn er twee takken, de fysieke inputs en de digitale. Beide opties worden geëxploreerd.
Een simpele app werd gemaakt volgens de richtlijnen voor digitale toegankelijkheid van Vlaanderen (Digitale Toegankelijkheid, z.d.). Op de app kan een gebruiker een traject selecteren en bevestigen. Men doet dit door te swipen over de kaders. Het traject wordt uitgesproken. Laat men los dan selecteert men het traject. Dit komt overeen met hoe IOS toestellen werken. Deze conventie zijn veel blinden gewent omdat IOS het meest gebruikt word.

Twee van de wijzerprototypes werden verder uitgewerkt met verschillende inputmogelijkheden bestaande uit knoppen en een rotary encoder.


Bijkomend zijn er verschillende bedieningsmethodes, terwijl de lay-out van de knoppen gelijk blijft. Volgend schema geeft de drie varianten weer.

Waarbij de feedbackpatronen als volgt beschreven zijn. In deze test word enkel aan, uit en bevestig gebruikt.


Verloop van de Test
We leggen de variant uit aan de testpersoon. Hierna vragen we om het toestel te leggen op de plaats waar ze het spontaan zouden bewaren. Dan geven we de testpersoon de locatie waar hij zogezegd naar toe moet. We volgen de persoon terwijl hij het toestel in gebruik neemt, de stappen doorloopt en de deur uit wandelt. Tijdens de test vragen we aan de personen om hun denkwijze luidop mee te delen. Na de testen vragen we aan de personen wat er goed liep en wat niet, en vragen we achter hun ervaring met de lay-out van de knoppen. Dit wordt herhaalt per variant.
Taakverdeling en regels
- Persoon 1 (Begeleider): Geeft de testpersoon het prototype en legt de werking van die variant uit.
- Persoon 2 (observeerder): Observeert en neemt foto’s Dataverzameling
Kwalitatieve data
- Welke opmerkingen maken de person uit zichzelf?
- Wat vonden ze van de test.
- Wat is hun ervaring met de button lay-out. Kwantitatieve data

- Hoe vaak moet de begeleider ingrijpen/helpen.
- Slaagt de testpersoon in zijn opdracht.
D5.1 | De UI is volledig bedienbaar zonder visuele informatie (geschikt voor blinden en slechtzienden). | Blinde deelnemers voltooien alle UI-taken (opstart, trajectkeuze, stop) blokkeringen bij ≥ 4 van 5 deelnemers.
D5.2 | De bedieningsknoppen zijn tactiel onderscheidbaar (voelbare rand, hoogteverschil, index). | Deelnemer identificeert elke knop correct; ≥ 4 van 5 deelnemers slagen bij eerste aanraking.

Materiaal

- Prototypes
- GSM met de juiste toegankelijks instellingen
- Notitie gerief
- Camera

Evaluatieblad Deel 1
Versie | Direct correcte houding | Opmerkingen | Argumentatie | Rang orde
| Ja / nee
| Ja / nee
| Ja / nee
| Ja / nee
| Ja / nee

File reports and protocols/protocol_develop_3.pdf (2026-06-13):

# Protocol Deelopdracht 3: Develop 3

Dit document bevat het protocol voor develop 3 en bestaat uit 2 testen.
Het eerste deel gaat in op CMF en kijkt nog eens waar het product zich plaats op de markt. De tweede test is een overkoepelde test waarin het volledige systeem tot nu toe getest wordt in de praktijk.
Respondenten:
Dirk | N=1 | 14/05/2026
Chris | N=1 | 18/05/2026
Oogatelier | N=3 | /

## Onderzoeksvragen

- CMF

Hoe ziet de afwerking van het product eruit?

- Kleur
- Materiaal
- Afwerking
- Markpositie
- Hoe wordt het product verkocht (herkend hulpmiddel/gadget)?
- Hoeveel wil een persoon betalen?
- Wat is de doelgroep hun mening over sociaal comfort van het product?
- Overkoepelde test
- Veel studies worden enkel in het labo getest en niet in echte omstandigheden. Daarom voeren we een test uit in de praktijk, waar meer variabelen en onzekerheden aanwezig zijn, om mogelijke problemen beter in kaart te brengen. Hier kun je de onderzoeksvraag formuleren als, hoe presteert het product in de praktijk.

## Deel 1 CMF en marktpositie

Testomgeving en Setup
Er wordt een variatie aan bestaande producten aan de correspondent voorgelecht. De volgorde dat deze producten overlopen worden is random voor elke persoon om geen valse vooroordelen te creëren.
Variabelen (Benchmark apparaten)
We werken met een set van referentieproducten met vergelijkbare afmetingen, zoals scheermachines, controllers en tandenborstels. Deze variëren in materiaalafwerking, gewicht en knoppresentatie.
Verloop van de Test
De correspondenten krijgen een voor een de producten voorgeschoteld. Op basis van een lijst voorbereide kerntermen gaan we op zoek naar welke CMF-eigenschappen best ons product ondersteunt.
Aan de correspondent worden volgende vragen gesteld:
- Vindt u het product comfortabel om vast te nemen? (Met nadruk op materiaalgevoel)
- Welke materialen denkt u te voelen?
- Zou dit product comfortabel zijn bij langdurig gebruik?
- Helpt het kleurencontrast bij het gebruik van het product?
- Kan u alle knoppen op het apparaat uitmaken?
- Zo ja, hoe komt het dat u deze knoppen duidelijk vindt?
- Zo nee, hoe zou u het beter kunnen vinden/maken? De antwoorden op de vragen werden opgeschreven en worden later in dit rapport besproken.
Hierna werd overgegaan naar vragen over de marktpositie van ons product.
Aan de correspondent werd snel nog eens het volledige concept uitgelecht en in wat het product in staat zou zijn als het op de markt komt. Daarna werden volgende vragen gesteld:
- Zou u interesse hebben als dit product op de markt beschikbaar was?
- Hoeveel zou u betalen voor dit product?
- Zou u het sneller aankopen als het terugbetaald moest worden?
- Zou u een abonnement aangaan voor verdere ondersteuning en continue updates van het product?

Taakverdeling en regels

- Persoon 1 (Begeleider): Geeft de verschillende prototypes aan de testpersoon, in helpt de testpersoon.
- Persoon 2 (observeerder): Observeert en neemt foto’s
- Persoon 3 (ondervrager): stelt de testpersoon de vragen en capteert de antwoorden
Dataverzameling
Kwalitatieve data
Welke opmerkingen maken de person uit zichzelf?
Waarom vinden mensen sommige referentieproducten beter dan andere? Antwoorden op de vragen.
Kwantitatieve data
Zoveel mogelijk bruikbare producten laten onderzoeken door de correspondenten. Materiaal
- Referentieproducten


- Notitie gerief
- Camera

## Deel 2 Overkoepelende test

In deze test leggen we een persoonlijk traject af van een gebruiker om de prestatie van het product te evalueren in de praktijk.
Waarbij de hoofdvraag is:
- hoe presteert het product in de praktijk
Testomgeving en Setup
De correspondenten zijn in de definitie fase bevraagt geweest in verband met trajecten waarbij ze het toestel zouden gebruiken. Hierbij zijn er twee concrete voorbeelden.
Dirk wil graag alleen gaan zwemmen. Jammer genoeg is er geen bushalte juist voor het zwembad. Hij moet wandelen van een verdere bushalte. Dit is een traject waarbij het hem niet lukt om het alleen af te wandelen. Het grootste struikelblok zijn de zebrapaden vinden en de open ruimtes oversteken.. Het traject ziet er als volgt uit.


Chris heeft een traject van Gent-Sint-Pieters naar het MSK in gent. Dit traject voeren we niet uit in Gent. Een alternatieve route wordt gemaakt in Gullegem. Die route ziet er als volgt uit.


Variabelen (De Prototype)
Het prototype bestaat uit de wegwijzer met controle doos die rond de nek wordt gedragen. De wijzer kan zowel met GPS als manueel bestuurd worden. Via een simpele webapplicatie is het verloop van het traject te volgen. Het prototype geeft een trilsignaal wanneer eden herkenningspunt bereikt is. De gesproken instructies worden door een begeleider gegeven.

Verloop van de Test
Traject Dirk
- Dirk komt toe met de bus aan bushalte Kortrijk weide met bus 66.
- De wegwijzer wordt aangegeven.
- Dirk wordt gevraag om zijn traject te starten
- Sherpa begint met de weg te wijzen
Herkenningspunt | Trilsignaal | Gespreken instructie
1 | Informatie | Start traject, straat volgen naar rechts.
2 | Aandacht | Zebrapad, Zebrapad oversteken daarna rechts de straat volgen.
3 | Aandacht | Paaltjes links volgens naar betonnen muur van tunnel.
4 | Informatie | Betonnen rand links volgen
5 | Informatie | Goot op grond volgen
6 | Informatie | Betonnen rand rechts volgen
7 | Informatie | Oversteek naar deur zwembad, volg wijzer tot aan paal
8 | Informatie | Bestemming bereikt

Traject Chris
- Met Chris wandelen we van haar huis naar het beginpunt
- De wegwijzer wordt aangegeven.
- Chris wordt gevraag om zijn traject te starten
- Sherpa begint met de weg te wijzen
Herkenningspunt | Trilsignaal | Gespreken instructie
1 | Informatie | Start traject, stoeprand volgen
2 | Informatie | Riooldeksel, stoeprand blijven volgen
3 | Aandacht | Oversteken bij verlaagde stoeprand, volg wijzer.
4 | Informatie | Paal op midden van het pad. Na paal rechter grasrand volgen.

5 | Informatie | Bij fietsrek links afslaan en grasrand rechts volgen.
6 | Informatie | Bestemming bereikt.


Taakverdeling en regels

- Persoon 1 (Begeleider): Staat in voor de veiligheid en correcte werking van het prototype, houdt het dashboard in de gaten in geeft de verbale instructies op de juiste momenten.
- Persoon 2 (observeerder): Observeert en neemt foto’s
- Persoon 3 (Bestuurder): Neemt over als de GPS fouten maakt. Dataverzameling en requierments
Kwalitatieve data
- Spontante opmerkingen
D3.4 | De gebruiker legt minder bekende trajecten af met zelfvertrouwen dankzij het systeem.
Likert 1–7 'Ik had er vertrouwen in dat ik de bestemming zou bereiken.' ≥ 5/7 gemiddeld.

Kwantitatieve data

D1.1 | Het systeem begeleidt de gebruiker doorheen een traject zodat elk herkenningspunt aantoonbaar bereikt wordt. | ≥ 100% van de herkenningspunten correct bereikt tijdens usability test (observatie per punt: ja/nee).
D1.2 | Het systeem geeft eenduidige feedback bij correcte richting, foute richting, herkenningspunten en gevaarlijke locaties | Deelnemer reageert correct (stopt, keert, bevestigt) op elk feedbacksignaal; ≥ 90% correcte reacties per sessie.

D1.3 | De gebruiker toont geen verwarring bij de start van het traject. | Geen observeerbare verwarring (pauze > 10 s, foutieve richting, verbale twijfel) in de eerste 60 s; getoetst bij ≥ 4 van 5 deelnemers.
D4.1 | Het gebruik van de witte stok wordt niet belemmerd door het product. | Deelnemer raakt geen obstakel dat door de stok gedetecteerd had moeten worden; 0 obstakelcontacten bij ≥ 3 deelnemers tijdens trajecttest.
D5.5 | Het systeem is bruikbaar na een enkele uitlegsessie van ≤ 20 minuten. | Na een introductiefase van max. 20 min voltooit de deelnemer het testparcours met ≤ 2 begeleidersinterventies.

Materiaal

- Prototypes
- Laptop met het traject
- Camera

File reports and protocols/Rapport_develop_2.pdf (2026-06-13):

# Sherpa develop 2 Rapport

## Onderzoeksvragen

- Houding en greep van de gebruiker

Eerdere tests tonen dat verschillende grepen invloed hebben op het polscomfort. Daarom ligt de focus op een ergonomisch ontwerp dat een correcte greep stimuleert en de belasting op hand en pols minimaliseert.

- Hoe kan de vorm van het product de houding van de gebruiker sturen naar een comfortabele en ergonomische houding?
- Interactie tussen toestel en gebruiker

Het product bevat verschillende functies. De gebruiker moet hiermee interageren. Specifiek wordt ingegaan op hoe men het toestel in werking stelt, een traject selecteert, start en stopt. Met als vraag:

- Hoe maken we de interacties ergonomisch met nadruk op een lage mentale belasting?
- Positie van de knoppen op product.

Gekoppeld aan de interactie wordt gekeken naar de positie van de input. Zowel de technische haalbaarheid als een aangename gebruikerservaring staan centraal.

- Wat is de beste plaatsing van de knopen op het product voor de doelgroep?

Respondenten:
Naam | Type visuele beperking | Datum | Locatie
Chris | Tunnelvisie minder dan 1% zicht | 8/04/2026 | Thuis
Dirk | Volledig blind | 10/04/2026 | Thuis
Mark | 10% restvisum | 8/5/2026 | Oogatelier
Siegfried | Legaal blind + licht mentale beperking | 8/5/2026 | Oogatelier
Mirjam | Volledig blind | 8/5/2026 | Oogatelier

## Deel 1 Houding en greep van de gebruiker

Protocol: Protocol_Develop_1
Dataverzameling
Kwalitatieve data
Welke opmerkingen maken de person uit zichzelf?
Waarom vinden mensen sommige versies beter dan andere? Kwantitatieve data
Nemen ze het toestel direct correct vast?
Welk versies springen eruit?
Resultaten
Versie | Direct correcte houding | Opmerkingen | Argumentatie | Rang orde
| 3/5 | Scherpe onderrand | | 1
| 5/5 | | | 3
| 3/5 | Oncomfortabel (tot de persoon wisselde van hand, rechts naar links) dan aangename greep | | 2
| 3/5 | Fragiel Oncomfortabele hoek | | 5
| 4/5 | Scherpe rand langs de onderkant, | | 4

Deel 2 Interactie tussen gebruiker en toestel
Testomgeving en Setup
We spel de interactie zo realistisch mogelijk na. De opdracht is om met het toestel een wandeling te maken naar de bakker. Het scenario loopt tot de testpersoon uit de deur is en het traject heeft gestart. De persoon wordt gebrieft hoe het toestel werkt.
- Gebruikers moeten het toestel leggen op een plaats waar ze het zouden opslaan (Waar?)
- Gebruikers maken zich zogezegd klaar om op stap te gaan. Hierbij nemen ze hun hulpmiddelen zoals een witte stock (Handen te kort?)
- Zetten zelfstandig het toestel en werking (Interactie onthouden en duidelijk?)
- Gebruiker selecteert een traject (Interactie onthouden en duidelijk?)
- Toestel in rusthouding (polsbandje)
- Start een traject (wanneer doen ze dit?)

## Resultaten

Greep
Zowel prototype 2 en 5 voldeden aan het criterium van D5.6. De vorm begeleide de gebruiker zodanig dat ze het toestel zoals behoren vasthielden. Versie 2 werd omgekeerd vastgenomen. Bij versie 3 was er verwarring door de asymmetrie. Bijkomend zorgde de asymmetrische variant voor verwarring bij het vastnemen. Blinden en slechtzienden worden doorgaans getraind om de witte stok in de rechterhand te houden, maar in de praktijk blijkt dit geen absolute regel. Verschillende deelnemers gaven aan regelmatig van hand te wisselen, afhankelijk van wat ze aftasten. Een asymmetrisch ontwerp houdt hiermee onvoldoende rekening.
➔ Het toestel moet bruikbaar zijn door zowel links als rechtshandige gebruikers.

Opbergen
Het toestel hoort duidelijk thuis bij de witte stok. Alle gebruikers halen aan dat ze het toestel ergens aan voordeur zouden leggen. Dit omdat daar ook hun andere hulpmiddelen gestockeerd liggen. Dirk gaf aan dat hij graag een duidelijk haakje heeft om iets op te hangen, hij doet dit met zijn witte stok. Het bandje van prototype gebruikte hij dan al ook direct om het toestel aan een kapstok te hangen.
Wanneer men het toestel moet opbergen bij het aankomen op locatie steekt de ene het in zijn handtas en de andere het in zijn jaszak. De algemene bevinding was dat de omvang geen probleem vormt, zolang het toestel compact genoeg blijft. Wat precies compact genoeg betekent werd concreet bij versie 3, door de asymmetrische vorm paste dit exemplaar minder vlot in zakken, wat aantoont dat niet alleen de afmetingen maar ook de vormgeving een rol speelt in de draagbaarheid.
APP
Een traject selecteren via de app verliep vlot alle deelnemers slaagden er in een traject te selecteren. Na de selectie ontstond er echter een twijfelmoment doordat het voor de gebruiker niet duidelijk was of het toestel effectief in werking was. Daarnaast viel op dat gebruikers na de uitleg vergaten het toestel aan te leggen en meteen naar de gsm grepen om een traject te selecteren.
Interactie toestel
We merkten dat gebruikers vlotter een traject selecteerden naarmate het aantal handelingen kleiner was, zelfs wanneer knoppen meerdere functies combineerden. De variant met de minste knoppen één knop voor aan/uit en één voor selecteren en bevestigen voldeed aan de criteria van D5.1 en D5.2. Bij de overige varianten ontstond na de uitleg meer verwarring over de precieze functie van elke knop, waardoor we vaker moesten assisteren om de werking te verduidelijken. Dit sluit aan bij de wet van Hick, waarbij minder keuzes en minder interpretaties leiden tot snellere besluitvorming.
De misverstanden die bij de app-varianten ontstonden, deden zich hier niet voor. Doordat alle interactie geïntegreerd is in het toestel, ontstaat er een natuurlijke volgtijdelijkheid waarbij de stappen vanzelf in de juiste volgorde worden uitgevoerd. Toestel aan zetten, traject selecteren, traject starten.
➔ De interactie vraagt zo min mogelijk stappen en heeft volgtijdelijkheid (constrains)

Tijdens de verkenningsfase van het toestel viel op dat deelnemers moeite hadden om de knoppen te lokaliseren. Zo probeerden meerdere deelnemers de wijzer in te drukken in plaats van de knop. Dit geeft aan dat de tactiele hiërarchie van het toestel onvoldoende duidelijk is de knoppen moeten zich als enige bedienbaar element laten voelen, zonder dat andere onderdelen verwarring wekken.

De rotary encoder viel niet in de smaak. Gebruikers draaiden te snel waardoor de trajectselectie niet ging. Daarnaast vraagt dit type bediening meer ruimte dan een eenvoudige knop, wat de compactheid van het toestel onder druk zet. Tot slot bleek de huidige uitvoering van het draaiwieltje te blijven haken bij het wegsteken, wat de bruikbaarheid in de praktijk verder bemoeilijkt.

D5.2 | De bedieningsknoppen zijn tactiel onderscheidbaar (voelbare rand, hoogteverschil, index).
Deelnemer identificeert
elke knop correct; ≥ 4
van 5 deelnemers
slagen bij eerste
aanraking.

Geen een van de
deelnemer vond alle
knoppen zonder
hulp. 0/5
Na de uitleg bij deel
2 konden 3/5
deelnemers de
knoppen

Multitasken
Tijdens de opdracht werd echter duidelijk dat het gelijktijdig beheren van gsm, prototype en hulpmiddel voor praktische problemen zorgt. Meerdere deelnemers maakten spontaan opmerkingen zoals "waar heb ik die gsm nu gelegd?", en één testpersoon vroeg expliciet of we het prototype even wilden vasthouden terwijl zij haar overige spullen op orde bracht. De opmerkingen over het jongleren met gsm en hulpmiddelen kwamen niet naar boven bij de prototypes waarbij alle interactie volledig in het toestel zelf was geïntegreerd.
Op basis van deze bevindingen kiezen we ervoor om alle interactie van de gebruiker te integreren in het toestel zelf, zonder gebruik van een externe app.
➔ Tijdens de play fase is er geen nood om een gsm te gebruiken Perceived kwaliteit
De deelnemers gingen opvallend voorzichtig om met de prototypes, wat erop wijst dat het toestel als fragiel werd ervaren. Dit is wellicht te wijten aan de afwerkingsgraad van de 3D-geprinte prototypes, die van nature minder kwaliteitsvol ogen dan een afgewerkt product. In de verdere uitwerking is het dan ook belangrijk dat het toestel een hoge perceived quality uitstraalt, het moet aanvoelen als iets dat tegen een stootje kan.
➔ Het ontwerp communiceert visueel en tactiel een gevoel van stevigheid en duurzaamheid.

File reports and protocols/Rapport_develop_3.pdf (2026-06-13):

# Rapport Deelopdracht 3: Develop 3

Dit document bevat het protocol voor de develop 3 fase, en bestaat uit 2 testen.
Het eerste deel gaat in op CMF en kijkt nog eens waar het product zich plaats op de markt. De tweede test is een overkoepelde test waarin het volledige systeem tot nu toe getest wordt in de praktijk.
Respondenten:
Dirk | N=1 | 14/05/2026
Chris | N=1 | 18/05/2026
Oogatelier | N=3 | /

## Onderzoeksvragen

- CMF

Hoe ziet de afwerking van het product eruit?

- Kleur
- Materiaal
- Afwerking
- Marktpositie
- Hoe wordt het product verkocht (herkend hulpmiddel/gadget)?
- Hoeveel wil een persoon betalen?
- Wat is de mening van de doelgroep over sociaal comfort van het product?
- Overkoepelde test
- Veel studies worden enkel in het labo getest en niet in echte omstandigheden. Daarom voeren we een test uit in de praktijk, waar meer variabelen en onzekerheden aanwezig zijn. Zo kunnen we mogelijke problemen beter in kaart brengen. Hier kan je de onderzoeksvraag formuleren als:

Hoe presteert het product in de praktijk?

## Deel 1 CMF en marktpositie

Testomgeving en Setup
Er wordt een variatie aan bestaande producten aan de correspondent voorgelegd.
De volgorde die deze producten overlopen is random voor elke persoon om zo geen valse vooroordelen te creëren.
Variabelen (Benchmark apparaten)
We werken met een set van referentieproducten met vergelijkbare afmetingen, zoals scheermachines, controllers en tandenborstels. Deze variëren in materiaalafwerking, gewicht en knoppresentatie.
Verloop van de Test
De correspondenten krijgen één voor één de producten voorgeschoteld. Op basis van een lijst voorbereide kerntermen gaan we op zoek naar welke CMF-eigenschappen best ons product ondersteunen.
Aan de correspondent worden volgende vragen gesteld:
- Vindt u het product comfortabel om vast te nemen? (Met nadruk op materiaalgevoel)
- Welke materialen denkt u te voelen?
- Zou dit product comfortabel zijn bij langdurig gebruik?
- Helpt het kleurencontrast bij het gebruik van het product?
- Kan u alle knoppen op het apparaat herkennen?
- Zo ja, hoe komt het dat u deze knoppen duidelijk vindt?
- Zo nee, hoe zou u het beter kunnen vinden/maken? De antwoorden op de vragen werden opgeschreven en worden later in dit rapport besproken.
Hierna werd overgegaan naar vragen over de marktpositie van ons product.
Aan de correspondent werd snel nog eens het volledige concept uitgelegd en in wat het product in staat zou zijn als het op de markt zou komen. We stelden volgende vragen:
- Zou u interesse hebben in het product mocht het op de markt beschikbaar zijn?
- Hoeveel zou u betalen voor dit product?
- Zou u het sneller aankopen als het terugbetaald zou worden?
- Zou u een abonnement aangaan voor verdere ondersteuning en continue updates van het product?

Taakverdeling en regels

- Persoon 1 (Begeleider): Geeft de verschillende prototypes aan de testpersoon, helpt de testpersoon.
- Persoon 2 (observeerder): Observeert en neemt foto’s.
- Persoon 3 (ondervrager): Stelt de testpersoon de vragen en capteert de antwoorden
Dataverzameling
Kwalitatieve data
Welke opmerkingen maken de testpersonen uit zichzelf?
Waarom vinden mensen sommige referentieproducten beter dan andere? Antwoorden op de vragen.
Kwantitatieve data
Zoveel mogelijk bruikbare producten laten onderzoeken door de correspondenten. Materiaal
- Referentieproducten


- Notitie materiaal
- Camera

## Resultaten Deel 1

Algemene resultaten uit de interviews:
- Vorm:
De vorm van het product moet de gebruiker begeleiden in hoe ze het product vast moeten houden. Toegepast op ons product zou het dus duidelijk moeten zijn voor de gebruiker waar de wijzer zich bevindt en dat dit deel naar voren moet wijzen. Uit vorig onderzoek is ook gebleken dat mensen ons product liefst op twee manieren gebruiken. Ofwel gebruiken ze de duim om de wijzer te voelen ofwel de wijsvinger. De knoppen moeten duidelijk zijn. Dit kan gedaan worden door deze een unieke vorm of uitstekende reliëf te geven.
- Kleur:
Bij het bepalen van de kleur is expliciet rekening gehouden met gebruikers die nog over een beperkte restvisus beschikken. Uit de user interviews kwam sterk naar voren dat de toevoeging van kleur niet louter esthetisch mag zijn, maar een duidelijke functionele meerwaarde moet bieden. Zoals het visueel accentueren van de interactieknoppen of het vergemakkelijken van het terugvinden van het product wanneer het is neergelegd. Voor slechtzienden vallen monochrome producten al snel weg tegen alledaagse oppervlakken, zoals een lichte balie of een donkere bijzettafel. Daarom is er bewust gekozen voor een ontwerp waarbij hoog kleurcontrast centraal staat, zodat de essentiële knoppen visueel geïsoleerd worden en de restvisus optimaal wordt benut.
- Materiaal:
Het eindproduct is bedoeld om mee te nemen naar buiten. Hierdoor zal het meer dan waarschijnlijk in contact komen met de verschillende weerselementen. Er is ook een grotere kans dat het product wel eens op de grond valt of een grote schok krijgt. Hierdoor is het belangrijk dat de materialen van het product sterk en impact bestendig zijn.
De respondenten vonden de producten die een vast materiaal hadden met daar rond een dun rubberachtig materiaal het beste. Het rubber materiaal zorgt voor grip tijdens het gebruik en absorbeert een groot deel van mogelijke schokken.
Een verschillend materiaalgebruik bij de knoppen hielp ook bij het vinden van de knoppen.
- Finish:
De respondenten verkozen over het algemeen een gladde finish op de knoppen.

Voor het eindproduct zou een satijn finish het beste zijn. Bij een glossy finish was er vrees dat het product sneller zou wegglijden uit de hand, en bij een matte finish was er vrees dat het sneller vuil zou worden en dat het moeilijker te reinigen zou zijn. Marktpositie van SHERPA
De correspondenten zagen zeker potentieel in het product. Als het eindproduct een volwaardig product zou zijn, zouden ze toch zeker overwegen om het te kopen. Mocht het product in de medische categorie komen te vallen zouden mensen met de juiste attesten een terugbetaling kunnen krijgen, wat meer motiveert om het product te kopen. Jammer genoeg is het zeer moeilijk om een product door alle controles te krijgen en te laten voldoen een de strenge wetgevingen in de medische wereld. Het moeten betalen van een abonnement is dan weer een negatief punt voor de gebruiker. Als de update echt het product met een grote stap zou verbeteren zouden de mensen het wel overwegen.
Er kwam nog een hele interessante vraag aan bod in de gesprekken, namelijk: wie is verantwoordelijk voor ongevallen tijdens het gebruik van een product als SHERPA? Hierop is geen direct antwoord te vinden. We zouden extra onderzoek moeten doen naar de geldende wetten in België en het buitenland.
Besluit
Hieronder worden de mogelijke materiaalkeuzes en productiemethodes besproken voor het eindproduct.

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

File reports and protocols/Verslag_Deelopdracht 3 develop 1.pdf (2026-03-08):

# Rapport Deelopdracht 3: Develop 1(N=5)

De user-tests die worden beschreven in dit document omvatten 3 deel testen.
De eerste twee testen gaan na welke type van aansturing het duidelijkst is voor onze doelgroep. Hierbij wordt gekeken naar hoe accuraat we een persoon een richting kunnen aanwijzen, en welke aanduidings-manier het duidelijkst is bij het afleggen van een traject.
De laatste test dient om duiding te krijgen hoe de doelgroep omgaat en reageert op feedback van het product.
Respondenten:
Naam | Type visuele beperking | Datum | Locatie
Chris | Tunnelvisie minder dan 1% zicht | 7/3/2026 | Thuis
Dirk | Volledig blind | 7/3/2026 | Thuis
Mark | 10% restvisum | 6/3/2026 | Oogatelier
Siegfried | Legaal blind + NAH + licht mentale hanidcap | 6/3/2026 | Oogatelier
Mirjam | Volledig blind | 6/3/2026 | Oogatelier
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

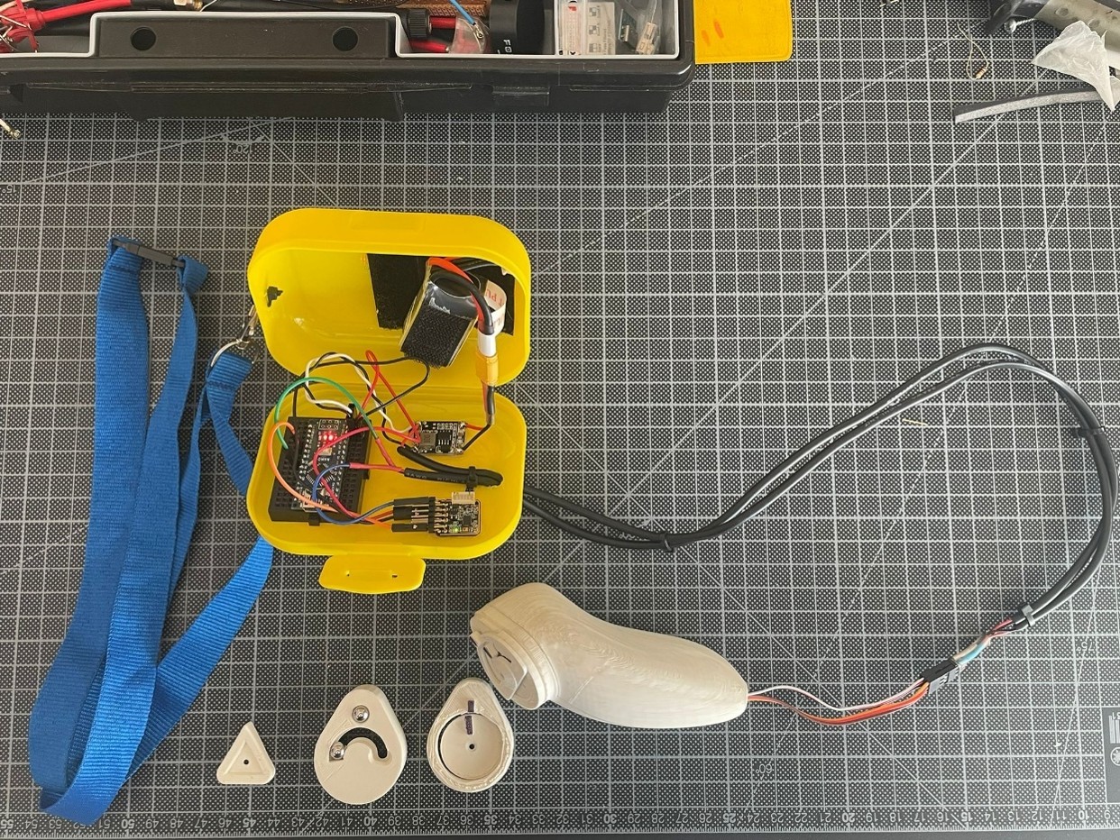
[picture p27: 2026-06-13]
img/Dev_1_prototype.jpg

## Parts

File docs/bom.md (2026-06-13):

# Bill of Materials (BOM) - Finaal prototype

Dit document bevat de volledige lijst met componenten, specificaties en de geschatte kosten voor de hardware-opstelling van het finaal prototype.
Volgende afbeelding toont de schakeling schematisch weer.

<p align="center">
  
</p>

## Projectonderdelen
* Seeed Studio XIAO ESP32-C3 (Microcontroller)
* Grove 9DOF IMU
* GPS Module (ATGM336H)
* MG90S Servo motor
* Trilmotor (Vibratiefeedback)
* 2x Mini drukknoppen (NO - Normally Open)
* 2S LiPo Batterij (8.4V)
* Spanningsregelaar (24-6V naar 5V Step-down)
* Passieve componenten: Pulldown-weerstanden, Filter ELCO (condensator) & Flyback diode
* Behuizing (PLA)
* Wrist strap
* 2x M2 10mm + 2x M3 20mm Self tapping screws

<p align="center">
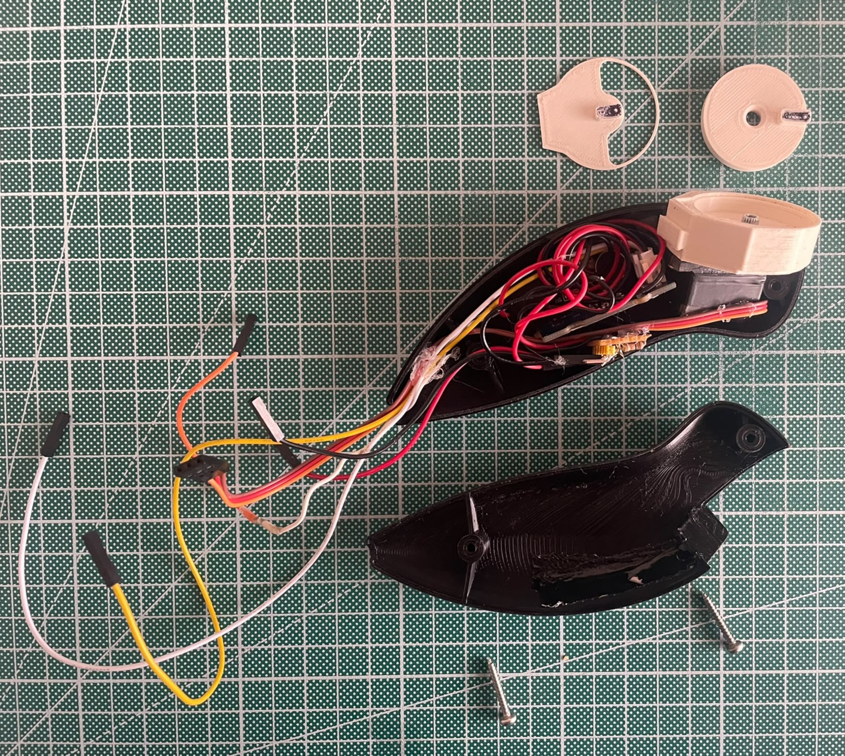
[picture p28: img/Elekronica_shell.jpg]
  
</p>

## BOM Overzichtstabel

| Component | Omschrijving & Specificaties | Leverancier / Link | Prijs (Schatting) |
| :--- | :--- | :--- | :--- |
| **Microcontroller** | Seeed Studio XIAO ESP32-C3 | [TinyTronics](https://www.tinytronics.nl/nl/development-boards/microcontroller-boards/met-wi-fi/seeed-studio-xiao-esp32-c3) | € 5,75 |
| **IMU Sensor** | Grove 9DOF IMU | [Kiwi Electronics](https://www.kiwi-electronics.com/nl/grove-imu-9dof-lcm20600plusak09918-3846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) | € 12,09 |
| **GPS Module** | ATGM336H GPS Module (met antenne) | [TinyTronics](https://www.tinytronics.nl/nl/communicatie-en-signalen/draadloos/gps/modules/atgm336h-gps-module) | € 10,50 |
| **Servo Motor** | MG90S Micro Servo | [TinyTronics](https://www.tinytronics.nl/nl/mechanica-en-actuatoren/motoren/servomotoren/mg90s-mini-servo) | € 5,00 |
| **Trilmotor** | Mini vibratiemotor (bijv. DFRobot Gravity) | [Open Circuit](https://opencircuit.be/product/gravity-vibration-motor-module-for-arduino) | € 2,20 |
| **Spanningsregelaar** | DC-DC Step Down Buck Converter (bijv. TC-9927140) | [Conrad](https://www.conrad.be/nl/p/tru-components-tc-9927140-spanningsregelaar-1-stuk-s-2481785.html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) | € 6,99 |
| **Batterij** | 2S LiPo Batterij (7.4V nominaal, 8.4V max) | [Amazon](https://www.amazon.com.be/-/nl/Zeee-Deans-T-stekker-Evader-Truggy/dp/B08X49GRHT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) | € 22.99 |
| **Knoppen** | 2x Mini NO-drukknop (Pushbutton) | [Amazon](https://www.amazon.nl/-/en/DAOKAI-Miniature-Instantaneous-Electronic-Components/dp/B09WVFHMSV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) | € 6,05 |
| **Kleine Componenten**| Weerstanden (pulldown), Filter ELCO, Flyback diode | [Amazon](https://www.amazon.nl/s?k=elektronica+componenten+assortiment) | € 15,00 |
| **Self Tapping Screws**| 2x M2 10mm, 2x M3 20mm Self tapping screws | [Amazon](https://www.amazon.com.be/-/en/Countersunk-Phillips-Stainless-Equipment-Furniture/dp/B08MVMSDCK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) | €13.99 |
| **Wrist Strap**| Elastische wrist strap | [Amazon](https://www.amazon.com.be/-/en/Replacement-Controller-Adjustable-Attach-Oculus/dp/B0DRV2NJZK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) | € 13,99 |
| **PLA**| 2x PLA filament (2 kleuren) *Netto verbruik: 60 gram*  | [Bol.com](https://www.bol.com/be/nl/p/polymaker-polyterra-pla-wit/9300000069648971/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) | € 22,49 per rol |
| **Totaal Bruto** | Bruto aanschafwaarde (inclusief grootverpakkingen en restmateriaal) | | € 159,53 |
| **TOTAAL Netto** | Waarde van het daadwerkelijk verbruikte materiaal | | **€ 86,22** |

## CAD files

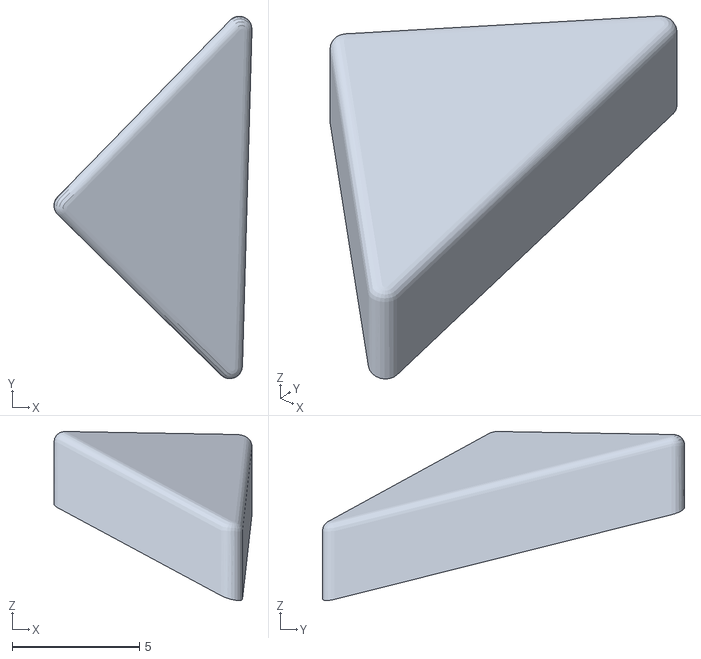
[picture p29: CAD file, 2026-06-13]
cad/Sherpa_V6_6.stl
7.79 x 14.3 x 6.65

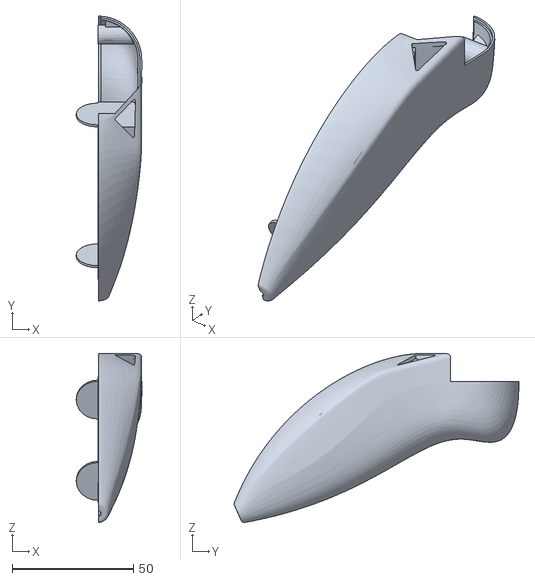
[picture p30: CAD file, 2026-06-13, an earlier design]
cad/Sherpa_V6_1.stl
27.0 x 117.4 x 69.6

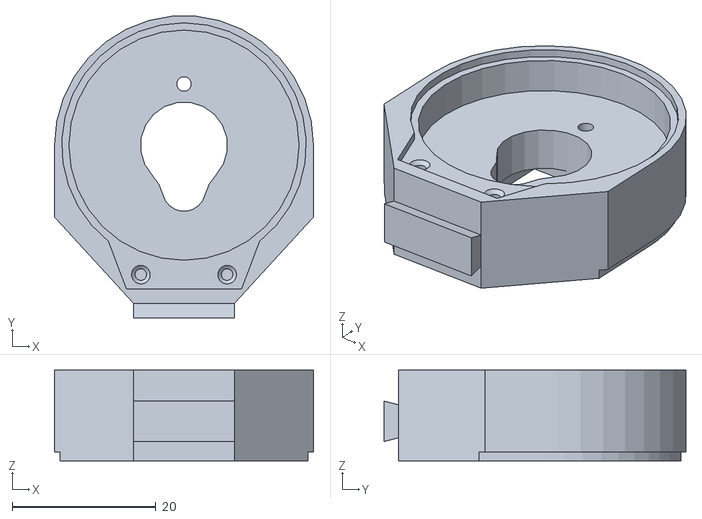
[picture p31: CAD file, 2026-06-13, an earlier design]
cad/Sherpa_V6_2.stl
36.0 x 41.9 x 12.6

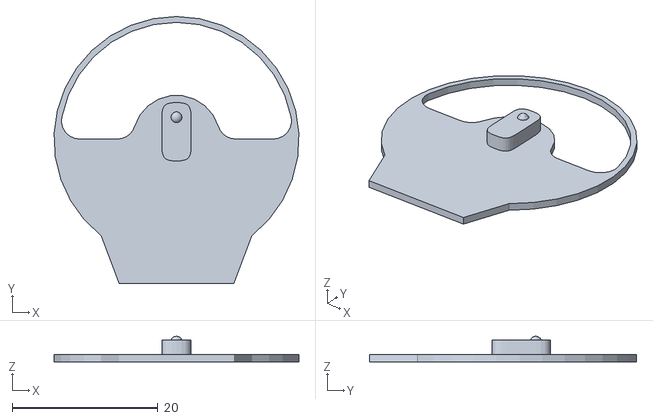
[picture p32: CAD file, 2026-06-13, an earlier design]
cad/Sherpa_V6_4.stl
33.6 x 36.6 x 3.52

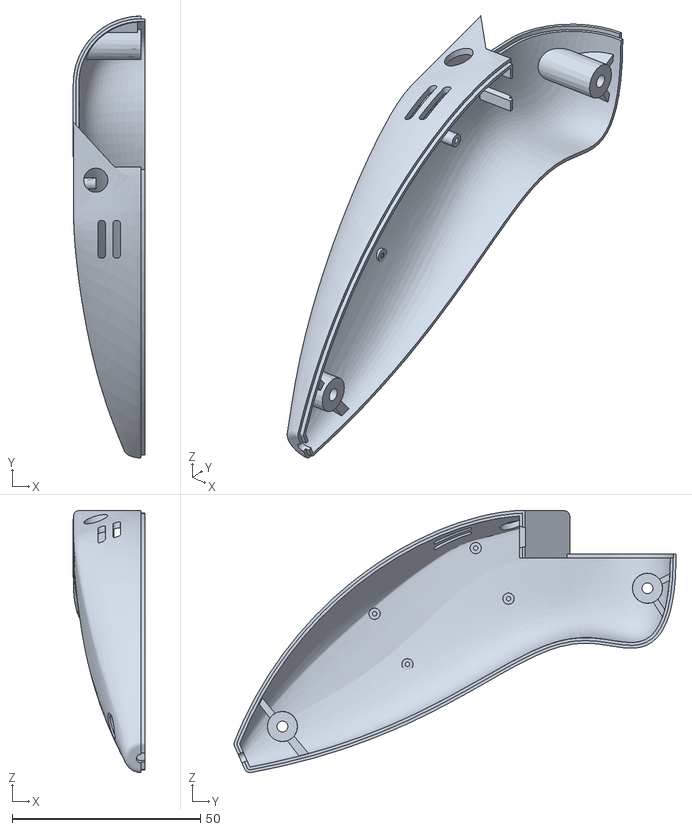
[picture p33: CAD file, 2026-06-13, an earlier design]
cad/Sherpa_V6.stl
19.0 x 117.4 x 69.6

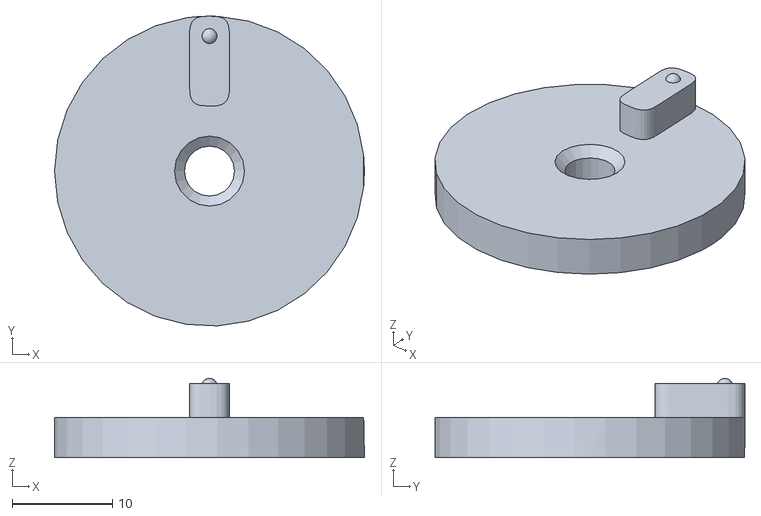
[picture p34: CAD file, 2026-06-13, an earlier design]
cad/Sherpa_V6_3.stl
31.0 x 31.0 x 7.92

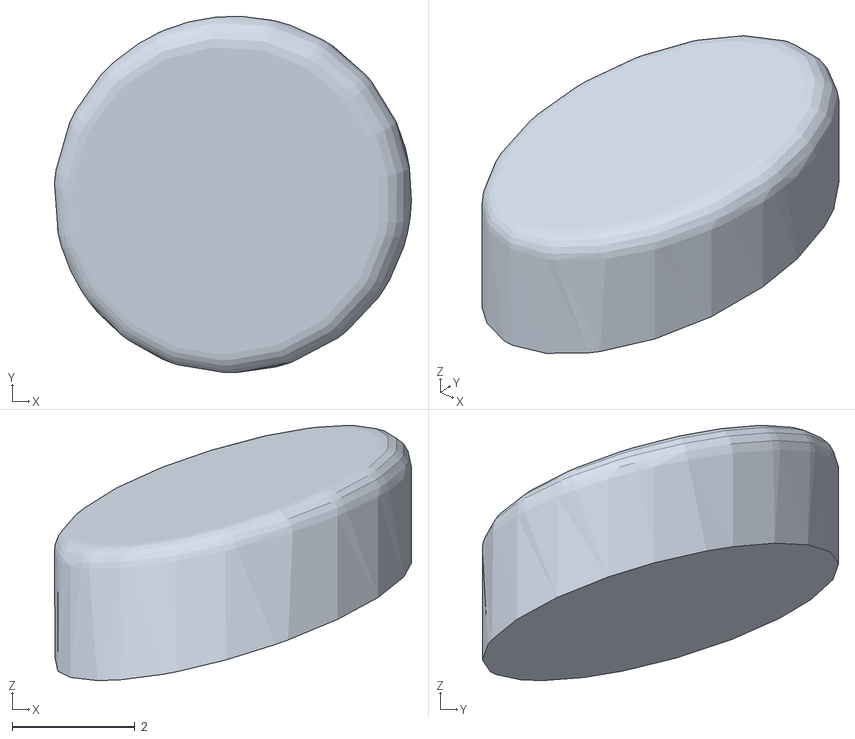
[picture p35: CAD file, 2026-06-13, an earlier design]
cad/Sherpa_V6_5.stl
5.82 x 5.81 x 4.16

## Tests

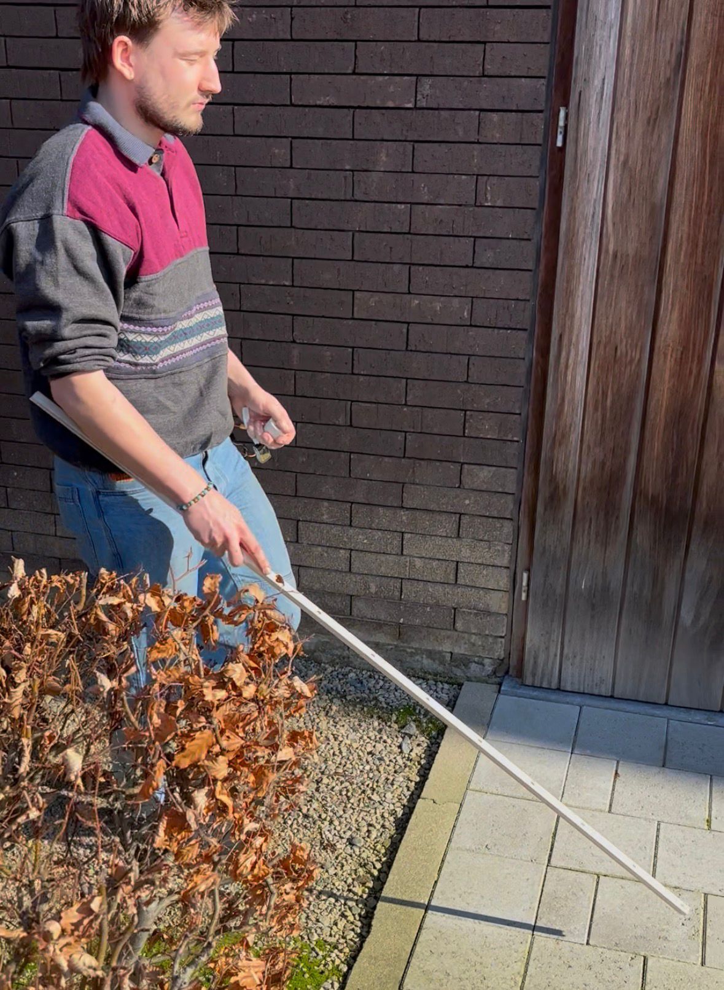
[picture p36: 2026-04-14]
img/ZelfTest.jpg

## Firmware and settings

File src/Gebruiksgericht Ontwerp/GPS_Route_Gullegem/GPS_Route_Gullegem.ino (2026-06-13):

//Bibliotheken
#include <TinyGPSPlus.h>        //GPS module 
//#include <SoftwareSerial.h>   //Seriele communicatie
#include "AK09918.h"            //magnetometer
#include "ICM20600.h"           //Accelero en gyro
#include <Wire.h>               //i2C
//#include <MadgwickAHRS.h>     //filter om gyro accelo en magneto te combineren madgwick
#include <HardwareSerial.h>     
#include <ESP32Servo.h>         //servolibrary
#include <Arduino.h>      
#include <math.h>
#include <stdint.h>
#include "HapticPattern.h"      //trilmotor patronen
#include "OneButton.h"          //knoppen logica 

#include <WiFi.h>
#include <WebServer.h>

// Set your AP credentials
const char* ssid = "Sherpa";
const char* password = "1234";

// Create a web server on port 80
WebServer server(80);



Servo Servo;                   //Servo object aanmaken

HapticPattern motor(D7);        //trilmotor object aanmaken

static const int RXPin = 8, TXPin = 9;  //rx en tx pin voor gps
static const uint32_t GPSBaud = 9600;   //GPSBaud rate


TinyGPSPlus gps; // Het TinyGPSPlus object

// Het filter object
//Madgwick filter;


// The serial connection to the GPS device
//SoftwareSerial ss(); //

//Waar willen we naar toe
double TargetLat; 
double TargetLong;

//waar zijn we nu
double CurrentLat; 
double CurrentLong;

int Bearing = 0;             //Naar waar moeten we 0 360
int Heading;             //Naar waar kijken we 0 360
int SignedHeading;       //Naar waar kijken we 180 -180


//IMU object aanmaken
AK09918 ak09918;
ICM20600 icm20600(true);
AK09918_err_type_t err;

int32_t x, y, z;   //ruwe x,y,z van magnetometer
float  mx, my, mz; //verwerkte x,y,z met offset van calibratie

float   Mag_x_dampened, Mag_y_dampened, Mag_z_dampened;
float   Mag_x_hor, Mag_y_hor;
float   Mag_pitch, Mag_roll;

float ax, ay, az; //ruwe acceleratie in x,y,z
float gx, gy, gz; //ruwe gyro in x,y,z

float gpitch, groll, gyaw, avector, apitch, aroll;
float gpitch_out, groll_out;
double roll, pitch;

// Find the magnetic declination at your location
// http://www.magnetic-declination.com/
double declination_shenzhen = 2.13;

#define Frequency 125                                                   // 8mS sample interval 
#define Sensitivity 32.8                                                // Gyro sensitivity (see data sheet)

#define Sensor_to_deg 1/(Sensitivity*Frequency)                         // Convert sensor reading to degrees
#define Sensor_to_rad Sensor_to_deg*DEG_TO_RAD                          // Convert sensor reading to radians

#define Loop_time 1000000/Frequency                                     // Loop time (uS)
long    Loop_start;                                                     // Loop start time (uS)


OneButton button_1(D3, false); // Pin 2
OneButton button_2(D2, false); // Pin 2

const int numLatAndLongs = 30; // Aantal coördinaten aangepast naar 26
double LatAndLongs[numLatAndLongs][2] = {
  {50.84351791259408, 3.199583806905673},
  {50.84354601710871, 3.199588600934886},
  {50.84356267574094, 3.199653787998074},
  {50.84358222641411, 3.199746388243405},
  {50.84357102276982, 3.199826471524791},
  {50.8435301934635, 3.19999442633681},
  {50.84351618348586, 3.200087512001366},
  {50.84347578889812, 3.200329492433738},
  {50.84344127078399, 3.200503973640461},
  {50.84340349397667, 3.200715350415644},
  {50.84337780650665, 3.200771205865209},
  {50.8433155490863, 3.200880802195201},
  {50.84324213801206, 3.201003634888817},
  {50.84313743451147, 3.20118925317262},
  {50.84311111454252, 3.201231914120035},
  {50.8431686512851, 3.201331367802704},
  {50.84320190609238, 3.201403935780052},
  {50.84324634406592, 3.201486277285546},
  {50.84330965109037, 3.201513657231716},
  {50.84335572514073, 3.2015437163629},
  {50.8433879623627, 3.201611450331614},
  {50.84345072193523, 3.201935545099357},
  {50.84349554351452, 3.202160041363336},
  {50.84350239434242, 3.202287311369529},
  {50.8435116025307, 3.202349298868643},
  {50.84368386243327, 3.202272524844345},
  {50.84371141436554, 3.202229632852147},
  {50.84367665813908, 3.202155990703988},
  {50.84365112960857, 3.202095180720579},
  {50.84365681572435, 3.202028216386121}
};
bool Gyro_synchronised = false;
//magnetometer calibratiewaarden, bepaald via calibratiesript
bool  Record_data = false; //calibratie uitvoerne JA/NEE
float offset_x = 7;
float offset_y = -24;
float offset_z = -4;
float scale_x = 1.30;
float scale_y = 0.92;
float scale_z = 0.87;

//gyro calibratiewaarden
float gx_cal, gy_cal, gz_cal;

//update snelheid controle a.d.v micros()
float HuidigeTijd = 0, LastUpdate = 0;
float UpdateFrequentie = 1000000/100; //1s in micros / 50 
float ActueleFrequentie = 0;

//servo pos
int pos = 0;
double Demping = 0.05;
int pos_out = 0;


//startup
bool Status_ON_OF = 0;

void setup()
{

  // Set ESP32 as Access Point
  WiFi.softAP(ssid, password);
  IPAddress IP = WiFi.softAPIP();

  server.on("/", handleRoot);
  server.begin();

  ESP32PWM::allocateTimer(0);
  ESP32PWM::allocateTimer(1);
  ESP32PWM::allocateTimer(2);
  ESP32PWM::allocateTimer(3);
  
  button_2.setPressMs(1000); // Zet de grens op 1000ms


  Serial.begin(115200);
  Serial1.begin(GPSBaud, SERIAL_8N1, RXPin, TXPin);
  
  pinMode(2, INPUT);
  pinMode(LED_BUILTIN, OUTPUT);
  
  Servo.setPeriodHertz(50); 
  Servo.attach(D10, 500, 2400); //ServoPin toekennen
  Servo.write(0); 
  
  // join I2C bus
  Wire.begin();
  
  err = ak09918.initialize();
  //ak09918.switchMode(AK09918_POWER_DOWN);
  ak09918.switchMode(AK09918_CONTINUOUS_100HZ);

  icm20600.initialize();
  icm20600.setAccScaleRange(RANGE_8G);
  icm20600.setGyroScaleRange(RANGE_1K_DPS);

  err = ak09918.isDataReady();
  while (err != AK09918_ERR_OK) {+
     Serial.println("Waiting Sensor");
     delay(100);
     err = ak09918.isDataReady();
    }

  if (Record_data == true)
  {
    calibrate_magnetometer();
  }

  Calibrate_gyro();
  LastUpdate = micros();

}

void handleRoot() {
  // Toestemming geven voor de browser (CORS)
  server.sendHeader("Access-Control-Allow-Origin", "*");

String data = String(gps.location.lat(), 6) + "," + 
                String(gps.location.lng(), 6) + "," + 
                String(Heading);

  server.send(200, "text/plain", data);
}

void loop()
{
  server.handleClient();

  button_1.tick();
  button_2.tick();
  motor.update();  // Update de trillingen

  updateGPS();
  
  GetPosition();
  GetBearing();
  GetCurrentHeading();
  NextPoint();

  StuurServo();

  Serial.print(" TargetLat:");
  Serial.print(TargetLat,6);
  Serial.print(F(","));
  Serial.print(" TargetLong:");
  Serial.print(TargetLong,6);
  Serial.print(F(","));

  Serial.print(" CurrentLat:");
  Serial.print(CurrentLat,6);
  Serial.print(F(","));
  Serial.print(" CurrentLong:");
  Serial.print(CurrentLong,6);
  Serial.print(F(","));
  
  Serial.print("pos:");

  Serial.print(pos);
  
  Serial.print(F(","));
 
  Serial.print(gps.distanceBetween(CurrentLat, CurrentLong, TargetLat,TargetLong));

   Serial.print(" Bearing:");

  Serial.print(Bearing);
  

  Serial.print("Heading:");
  Serial.println(Heading);

}

void GetBearing()
{
  Bearing = TinyGPSPlus::courseTo(CurrentLat, CurrentLong, TargetLat, TargetLong);
}



void NextPoint() {
  float Distance = gps.distanceBetween(CurrentLat, CurrentLong, TargetLat, TargetLong);
  
  unsigned long CurrentTime = millis();
  static unsigned long ArrivalTime = 0;
  static bool TargetHit = false;
  static int index = 1;


  if (Distance < 2.0 && !TargetHit) { 
    ArrivalTime = CurrentTime;
    TargetHit = true;
    Serial.println("TargetHit");
  }


  if (TargetHit) {
    if (CurrentTime - ArrivalTime > 1000) { 
      
      TargetLat = LatAndLongs[index][0];
      TargetLong = LatAndLongs[index][1]; 
      
      index++;
      if (index >= numLatAndLongs) {
        index = 0; 
      }

      TargetHit = false;
      Serial.println("NextTarget");
    }
  }
}

void GetCurrentHeading() 
{

  if ((micros() - LastUpdate) >= 8000){
    LastUpdate = micros();

    // get acceleration
    ax =  icm20600.getRawAccelerationX();
    ay =  icm20600.getRawAccelerationY();
    az =  icm20600.getRawAccelerationZ();

    // get gyro
    gx = icm20600.getRawGyroscopeX(); 
    gy = - icm20600.getRawGyroscopeY();
    gz = - icm20600.getRawGyroscopeZ();

    // get magneto
    ak09918.getData(&x, &y, &z); 
    mx = + (x - offset_x) * scale_x;
    my = + (y - offset_y) * scale_y;
    mz = + (z - offset_z) * scale_z;

    //gyro hoeksnelheid omrekening naar hoek (integratie) LET OP!! doorloopsnelheid bepaald dt
    //dit stuk code moet altijd aan 125HZ lopen = 8ms per update
    groll += (gx - gx_cal) * Sensor_to_deg;
    gpitch += (gy - gy_cal) * Sensor_to_deg;
    gyaw += (gz - gz_cal) * Sensor_to_deg;

    float gpitch_temp = gpitch;
    float groll_temp = groll;

      // ----- Compensate pitch and roll for gyro yaw
    gpitch += groll_temp * sin((gz - gz_cal) * Sensor_to_rad);            // Transfer the roll angle to the pitch angle if the Z-axis has yawed
    groll -= gpitch_temp * sin((gz - gz_cal) * Sensor_to_rad);            // Transfer the pitch angle to the roll angle if the Z-axis has yawed

      // ----- Accelerometer angle calculations
    avector = sqrt((ax * ax) + (ay * ay) + (az * az));   // Calculate the total (3D) vector
    apitch = asin((float)ax / avector) * RAD_TO_DEG;                         //Calculate the pitch angle 
    aroll =  asin((float)ay / avector) * RAD_TO_DEG;                         //Calculate the roll angle

    apitch -= -1.0f;                                             //Accelerometer calibration value for pitch
    aroll -= 0.6f;                                               //Accelerometer calibration value for roll


  // ----- Correct for any gyro drift
  if (Gyro_synchronised)
  {
    // ----- Gyro & accel have been synchronised
    gpitch = gpitch * 0.75 + apitch * 0.25;        //Correct the drift of the gyro pitch angle with the accelerometer pitch angle
    groll = groll * 0.75 + aroll * 0.25;           //Correct the drift of the gyro roll angle with the accelerometer roll angle
  }
  else
  {
    // ----- Synchronise gyro & accel
    gpitch = apitch;                                       //Set the gyro pitch angle equal to the accelerometer pitch angle
    groll = aroll;                                         //Set the gyro roll angle equal to the accelerometer roll angle
    Gyro_synchronised = true;                                             //Set the IMU started flag
  }

  // ----- Dampen the pitch and roll angles
  gpitch_out = gpitch_out * 0.9 + gpitch * 0.1;   //Take 90% of the output pitch value and add 10% of the raw pitch value
  groll_out = groll_out * 0.9 + groll * 0.1;      //Take 90% of the output roll value and add 10% of the raw roll value

  
  Mag_pitch = - gpitch * DEG_TO_RAD; 
  Mag_roll = groll * DEG_TO_RAD;


  // ----- Apply the standard tilt formulas
  float p = Mag_pitch; 
  float r = Mag_roll;

   // Bereken de horizontale componenten
  Mag_x_hor = mx * cos(p) + my * sin(r) * sin(p) + mz * cos(r) * sin(p);
  Mag_y_hor = my * cos(r) - mz * sin(r);
 

  // ----- Dampen any data fluctuations
  Mag_x_dampened = Mag_x_dampened * 0.9 + Mag_x_hor * 0.1;
  Mag_y_dampened = Mag_y_dampened * 0.9 + Mag_y_hor * 0.1;

  // ----- Calculate the heading
  Heading = atan2(Mag_y_dampened,Mag_x_dampened ) * RAD_TO_DEG;  // Magnetic North

 
    // Voeg declinatie toe
    Heading += declination_shenzhen;

    SignedHeading = Heading;

    // Normaliseer naar 0-360
  if (Heading > 360.0) Heading -= 360.0;
  if (Heading < 0.0) Heading += 360.0;

  if (SignedHeading > 180) SignedHeading -= 360;
  if (SignedHeading < - 180) SignedHeading += 360;


  }
}


//-------------------------------------------------------------------------

void updateGPS()
{
  while (Serial1.available() > 0) //GPS beschikbaar
  {
    gps.encode(Serial1.read());   // lees GPS data
  }

  if (millis() > 5000 && gps.charsProcessed() < 10) //Doet de gps wat hij moet doen? Nee, geef foutmelding
  {
    Serial.println(F("No GPS detected: check wiring."));
  }
}

//-------------------------------------------------------------------------


void GetPosition()
{
  if (gps.location.isValid())
  {
    CurrentLat = gps.location.lat();
    CurrentLong = gps.location.lng();
  }
  else
  {
    Serial.print("GPS_Location_NOT_Valid"  );
  }
}


float convertRawAcceleration(int aRaw) {
  // since we are using 2 g range
  // -2 g maps to a raw value of -32768
  // +2 g maps to a raw value of 32767

  float a = (aRaw * 2.0) / 32768.0;
  return a;
}

float convertRawGyro(int gRaw) {
  // since we are using 500 degrees/seconds range
  // -500 maps to a raw value of -32768
  // +500 maps to a raw value of 32767
  
  float g = (gRaw * 500.0) / 32768.0;
  return g;
}




//rekent delta uit en stuur de servo aan, bij delta 0 geeft de trilmotor een signaal
void StuurServo()
{

  int Delta = Bearing - Heading;

  if (Delta > 180)  Delta -= 360;
  if (Delta < -180) Delta += 360;

  pos = 90 + 1.6 * Delta;

  pos = constrain(pos, 10, 170);

  pos_out = pos + Demping * (pos - pos_out);

  static unsigned long LaatsteTrigger = 0;
  unsigned long HuidigeTijd = millis();
  
  if(abs(Delta) <= 1)
  {
    if (HuidigeTijd - LaatsteTrigger > 500)
    {
      motor.trigger(5);
      LaatsteTrigger = HuidigeTijd;
    }

  }

  static int ServoBuffer = 0;
    
  if(++ServoBuffer >= 10)
  {
    ServoBuffer = 0;
    Servo.write(pos_out);
  }  
}



void Calibrate_gyro()
{
  // ----- Display calibration message

  Serial.print("Calibrating gyro");                        //Print text to screen

  // ----- Calibrate gyro
  for (int counter = 0; counter < 2000 ; counter ++)    //Run this code 2000 times
  {
    Loop_start = micros();
    if (counter % 125 == 0)Serial.print(".");              //Print a dot on the LCD every 125 readings
    
    // get gyro
    gx = icm20600.getRawGyroscopeX(); 
    gy = - icm20600.getRawGyroscopeY();
    gz = - icm20600.getRawGyroscopeZ();    

    gx_cal += gx;                               //Add the gyro x-axis offset to the gyro_x_cal variable
    gy_cal += gy;                               //Add the gyro y-axis offset to the gyro_y_cal variable
    gz_cal += gz;                               //Add the gyro z-axis offset to the gyro_z_cal variable
    while (micros() - Loop_start < Loop_time);           // Wait until "Loop_time" microseconds have elapsed
  }
  gx_cal /= 2000;                                   //Divide the gyro_x_cal variable by 2000 to get the average offset
  gy_cal /= 2000;                                   //Divide the gyro_y_cal variable by 2000 to get the average offset
  gz_cal /= 2000;                                   //Divide the gyro_z_cal variable by 2000 to get the average offset
}


void calibrate_magnetometer()
{
  // ----- Locals
  int mag_x, mag_y, mag_z;
  int status_reg_2;                                               // ST2 status register

  int32_t mag_x_min =  32767;                                         // Raw data extremes
  int32_t mag_y_min =  32767;
  int32_t mag_z_min =  32767;
  int32_t mag_x_max = -32768;
  int32_t mag_y_max = -32768;
  int32_t mag_z_max = -32768;

  float chord_x,  chord_y,  chord_z;                              // Used for calculating scale factors
  float chord_average;

  // ----- Display calibration message
  Serial.print("Rotate Compass");                                    // Print text to screen

  // ----- Record min/max XYZ compass readings
  for (int counter = 0; counter < 16000 ; counter ++)             // Run this code 16000 times
  {
     if (counter % 125 == 0)Serial.print(".");
    Loop_start = micros();                                        // Start loop timer
        // ----- Find max/min xyz values
        ak09918.getData(&x, &y, &z); 

        mag_x_min = min(x, mag_x_min);
        mag_x_max = max(x, mag_x_max);
        mag_y_min = min(y, mag_y_min);
        mag_y_max = max(y, mag_y_max);
        mag_z_min = min(z, mag_z_min);
        mag_z_max = max(z, mag_z_max);
  
    
    delay(2);                                                     // Time interval between magnetometer readings
  }

  // ----- Calculate hard-iron offsets
  offset_x = (mag_x_max + mag_x_min) / 2;                     // Get average magnetic bias in counts
  offset_y = (mag_y_max + mag_y_min) / 2;
  offset_z = (mag_z_max + mag_z_min) / 2;

  // ----- Calculate soft-iron scale factors
  chord_x = ((float)(mag_x_max - mag_x_min)) / 2;                 // Get average max chord length in counts
  chord_y = ((float)(mag_y_max - mag_y_min)) / 2;
  chord_z = ((float)(mag_z_max - mag_z_min)) / 2;

  chord_average = (chord_x + chord_y + chord_z) / 3;              // Calculate average chord length

  scale_x = chord_average / chord_x;                          // Calculate X scale factor
  scale_y = chord_average / chord_y;                          // Calculate Y scale factor
  scale_z = chord_average / chord_z;                          // Calculate Z scale factor

  // ----- Record magnetometer offsets
  /*
     When active this feature sends the magnetometer data
     to the Serial Monitor then halts the program.
  */
  if (Record_data == true)
  {
    // ----- Display data extremes
    Serial.print("XYZ Max/Min: ");
    Serial.print(mag_x_min); Serial.print("\t");
    Serial.print(mag_x_max); Serial.print("\t");
    Serial.print(mag_y_min); Serial.print("\t");
    Serial.print(mag_y_max); Serial.print("\t");
    Serial.print(mag_z_min); Serial.print("\t");
    Serial.println(mag_z_max);
    Serial.println("");

    // ----- Display hard-iron offsets
    Serial.print("Hard-iron: ");
    Serial.print(offset_x); Serial.print("\t");
    Serial.print(offset_y); Serial.print("\t");
    Serial.println(offset_z);
    Serial.println("");

    // ----- Display soft-iron scale factors
    Serial.print("Soft-iron: ");
    Serial.print(scale_x); Serial.print("\t");
    Serial.print(scale_y); Serial.print("\t");
    Serial.println(scale_z);
    Serial.println("");

    // ----- Halt program
    while (true);                                       // Wheelspin ... program halt
  }
}

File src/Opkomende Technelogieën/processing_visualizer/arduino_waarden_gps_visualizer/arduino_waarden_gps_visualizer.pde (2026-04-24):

import java.util.*;
import processing.serial.*;

// --- ARDUINO SETTINGS ---
boolean useArduino = true; 
Serial myPort;

class GPSPoint {
  float lat, lon;
  GPSPoint(float lat, float lon) {
    this.lat = lat;
    this.lon = lon;
  }
}

// We use a standard ArrayList, but we will lock it when reading/writing
ArrayList<GPSPoint> path = new ArrayList<GPSPoint>();

float[][] rawCoordinates = {
  {50.822040450878426, 3.2502464605204984},
  {50.82237933663994,  3.249940688686364},
  {50.822684331722385, 3.2496992898699424}
};

int currentIndex = 0;
float t = 0;
float segmentDuration = 2.5;
int lastTime;
float minLat, maxLat, minLon, maxLon;

HashSet<Integer> markerPoints = new HashSet<Integer>();
int hazardPoint = -1;

boolean isPaused = false;
int pauseStartTime = 0;
int pauseDuration = 5000;

boolean started = false;
int startTime;
boolean arrived = false;
float lastBearing = 0;

ArrayList<PVector> confetti = new ArrayList<PVector>();

void setup() {
  size(900, 700);

  if (useArduino) {
    // 1. CRASH PREVENTION: Safe Port Selection
    String[] ports = Serial.list();
    if (ports.length == 0) {
      println("CRITICAL ERROR: No Arduino found! Plug it in and restart.");
      useArduino = false; // Fall back to simulation safely
    } else {
      try {
        // NOTE: You might need to change ports[0] to ports[1] or ports[2] 
        // depending on where your Arduino is plugged in.
        String portName = ports[0]; 
        myPort = new Serial(this, portName, 9600);
        myPort.bufferUntil('\n'); 
        println("Successfully connected to: " + portName);
      } catch (Exception e) {
        println("ERROR: Could not open port. Is the Serial Monitor open in the Arduino IDE? Close it!");
        useArduino = false;
      }
    }
  } 
  
  if (!useArduino) {
    // Simulation fallback
    for (int i = 0; i < rawCoordinates.length; i++) {
      path.add(new GPSPoint(rawCoordinates[i][0], rawCoordinates[i][1]));
    }
    markerPoints.add(1);
    hazardPoint = 2;
    computeBounds();
  }

  startTime = millis();
  lastTime = millis();
}

// 2. CRASH PREVENTION: Safe Serial Parsing & Thread Locking
void serialEvent(Serial myPort) {
  try {
    String inString = myPort.readStringUntil('\n');
    if (inString != null) {
      inString = trim(inString); 
      
      // Ignore empty strings to prevent array out of bounds
      if (inString.length() < 3) return; 
      
      String[] coords = split(inString, ','); 
      
      if (coords.length == 2) {
        float incomingLat = float(coords[0]);
        float incomingLon = float(coords[1]);
        
        // Prevent NaN (Not a Number) crashes if text was sent instead of numbers
        if (!Float.isNaN(incomingLat) && !Float.isNaN(incomingLon)) {
          
          // LOCK the path array so draw() can't read it while we add to it
          synchronized(path) {
            path.add(new GPSPoint(incomingLat, incomingLon));
            computeBounds();
          }
          println("Live Data: " + incomingLat + ", " + incomingLon);
        }
      }
    }
  } catch (Exception e) {
    // If absolutely anything goes wrong reading the text, catch it silently
    println("Skipped a corrupted data packet from Arduino.");
  }
}

void computeBounds() {
  if (path.size() == 0) return;
  minLat = maxLat = path.get(0).lat;
  minLon = maxLon = path.get(0).lon;
  for(GPSPoint p : path){
    minLat = min(minLat, p.lat);
    maxLat = max(maxLat, p.lat);
    minLon = min(minLon, p.lon);
    maxLon = max(maxLon, p.lon);
  }
  
  if (minLat == maxLat) { minLat -= 0.0001; maxLat += 0.0001; }
  if (minLon == maxLon) { minLon -= 0.0001; maxLon += 0.0001; }
}

PVector gpsToScreen(GPSPoint p) {
  float x = map(p.lon, minLon, maxLon, 50, width - 50);
  float y = map(p.lat, minLat, maxLat, height - 50, 50);
  return new PVector(x, y);
}

float calculateBearing(GPSPoint a, GPSPoint b){
  float lat1 = radians(a.lat), lat2 = radians(b.lat);
  float dLon = radians(b.lon - a.lon);
  float y = sin(dLon) * cos(lat2);
  float x = cos(lat1) * sin(lat2) - sin(lat1) * cos(lat2) * cos(dLon);
  return (degrees(atan2(y, x)) + 360) % 360;
}

void draw(){
  background(250);

  // 3. CRASH PREVENTION: Lock the path while drawing
  synchronized(path) {
    if (path.size() < 2) {
      fill(0);
      textAlign(CENTER, CENTER);
      text("Waiting for valid GPS data from Arduino...", width/2, height/2);
      return;
    }

    float dt=(millis()-lastTime)/1000.0;
    lastTime=millis();

    if(!started && millis()-startTime>2000) started=true;

    stroke(0);
    noFill();
    beginShape();
    for(GPSPoint p:path){
      PVector v=gpsToScreen(p);
      vertex(v.x,v.y);
    }
    endShape();

    for(int i=0;i<path.size();i++){
      PVector p=gpsToScreen(path.get(i));
      if(markerPoints.contains(i)){
        fill(0,200,0); ellipse(p.x,p.y,10,10);
      }
      if(i==hazardPoint && (millis()/300)%2==0){
        fill(255,0,0); ellipse(p.x,p.y,12,12);
      }
    }

    GPSPoint a=path.get(currentIndex);
    GPSPoint b=path.get(min(currentIndex+1,path.size()-1));

    PVector pa=gpsToScreen(a);
    PVector pb=gpsToScreen(b);

    PVector pos=PVector.lerp(pa,pb,t);

    boolean isMovingNow = started && !isPaused && !arrived;
    drawStickman(pos.x,pos.y,isMovingNow);

    fill(255,140,0);
    ellipse(pb.x,pb.y,10,10);

    if(!isPaused && started){
      lastBearing=calculateBearing(a,b);
    }

    drawArrow(width-100,height-100,lastBearing);

    if(started && !arrived && !isPaused){
      t += dt / segmentDuration;

      if(t>=1){
        t=0;
        if(currentIndex < path.size() - 2) {
          currentIndex++;
          
          if(markerPoints.contains(currentIndex)||currentIndex==hazardPoint){
            isPaused=true;
            pauseStartTime=millis();
          }
        } else if (!useArduino) {
          arrived=true;
          createConfetti();
        }
      }
    }
  } // End of synchronized block

  if(isPaused && millis()-pauseStartTime>pauseDuration){
    isPaused=false;
  }

  drawConfetti();
  drawLegend();
}

// --- UTILITIES (Stickman, Arrow, Legend, Confetti remain unchanged) ---
void drawStickman(float x, float y, boolean isMoving){
  stroke(0); fill(0,120,255); ellipse(x, y-10, 10, 10);
  line(x, y-5, x, y+12); float walk = isMoving ? sin(frameCount*0.1)*8 : 0;
  line(x,y,x-8,y+walk); line(x,y,x+8,y-walk); line(x,y+12,x-6,y+22+walk); line(x,y+12,x+6,y+22-walk);
}

void drawArrow(float x,float y,float angle){
  pushMatrix(); translate(x,y); rotate(radians(angle)); fill(40);
  beginShape(); vertex(0,-30); vertex(-10,10); vertex(10,10); endShape(CLOSE);
  popMatrix(); fill(0); textAlign(CENTER); text(int(angle)+"°",x,y+40);
}
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

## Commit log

2026-03-08 foto des
2026-04-21 Opkomende technologieen + arduino toegevoegd
2026-05-05 Dubbel uitvoeren van servo.write, code opgekuist
2026-05-05 demping toegevoegd Servo Sturing
2026-06-12 BOM aanngepast naar finaal
2026-06-12 BOM links aangepast
2026-06-13 Methdologie en BOM
2026-06-13 stl in CAD map
    [Sherpa_V6.stl, Sherpa_V6_1.stl, Sherpa_V6_2.stl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]
2026-06-13 error gefix bij cad read me
